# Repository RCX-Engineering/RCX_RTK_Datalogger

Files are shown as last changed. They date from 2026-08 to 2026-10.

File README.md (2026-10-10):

# RCX RTK Datalogger & RCX RTK Base

The **RCX RTK Datalogger**, developed by **RCX Engineering**, is an open-source RTK GNSS data-acquisition system developed for motorsports. The project combines a 20 Hz quad-band omni-constellation GNSS receiver, 6-axis IMU, vehicle CAN data, local SD logging, an onboard display, Wi-Fi connectivity for RTCM (RTK) data, a web interface for device management, and Bluetooth (BLE) telemetry compatible with the RaceCapture protocol for connectivity to datalogging software like SoloStorm.

The repository contains firmware for two closely related devices:

- **RCX RTK Datalogger (rover)** — installed in the vehicle to acquire GNSS, IMU, and CAN data and stream/log the resulting telemetry.
- **RCX RTK Base** — a portable reference station that generates RTK correction data for use where a suitable nearby public base is unavailable.

The rover and base share identical hardware. Their primary difference is the firmware and the interfaces enabled for each role.

> **Project status:** The RCX RTK Datalogger and RCX RTK Base are actively developed engineering/prototype platforms. They have been tested in real autocross environments, but hardware, firmware, configuration, and data-processing methods continue to evolve. 

## What Is RTK GNSS?

**GNSS** (Global Navigation Satellite System) is the general term for satellite-positioning systems such as GPS, Galileo, GLONASS, and BeiDou. A conventional standalone GNSS receiver calculates its position from the timing and ranging information broadcast by the satellites. Even with a good modern multi-band receiver, the resulting position still contains errors from satellite clocks and orbits, atmospheric propagation, multipath, receiver noise, and satellite geometry.

**RTK — Real-Time Kinematic — GNSS adds a fixed reference base station at a known location.** The base observes many of the same satellites and many of the same error sources as the moving rover. It generates correction data and sends it to the rover, typically as an RTCM stream over a radio or an Internet-based NTRIP connection. The rover combines those corrections with multi-frequency carrier-phase measurements and resolves the carrier-cycle ambiguities required for an **RTK Fixed** solution.

The important difference is scale: ordinary standalone GNSS positioning is generally a **meter-scale** measurement, while a good RTK Fixed solution can provide **centimeter-scale relative positioning**. The exact accuracy is installation and environment-dependent, and absolute accuracy also depends on how accurately the base position is known.

| | Standalone GNSS | RTK GNSS |
|---|---|---|
| Reference station | Not required | Required, directly or through an RTK network |
| Correction data | None | Real-time base/network corrections |
| Primary measurements | Satellite ranging; receiver-dependent use of carrier data | Multi-frequency carrier-phase positioning with corrections |
| Typical positioning scale | Meter level | Centimeter level when RTK Fixed |
| Sensitivity to multipath/obstruction | Significant | Still significant; RTK cannot eliminate local multipath or blocked satellites |
| Best suited for | Navigation, timing, general track mapping | Precise trajectory comparison, surveying, machine control, and high-resolution motorsports analysis |

For motorsports, the benefit is not simply a prettier GPS trace. When two runs differ by only a few inches at an apex or slalom cone, meter-scale position uncertainty can be larger than the driving difference being studied. Centimeter-class RTK data makes those differences directly measurable and substantially improves confidence when correlating vehicle position with IMU and CAN data.

RTK also improves **repeatability**: data from different runs, vehicles, or days can be placed in the same coordinate frame when they use a properly established reference. This enables meaningful comparison of line choice, cone clearance, braking and acceleration locations, vehicle attitude, and derived quantities such as wheel trajectories and slip behavior.

RTK does **not** inherently mean a high update rate. Position accuracy and sample rate are separate characteristics. The RCX RTK Datalogger combines RTK positioning with **20 Hz** GNSS output specifically so that centimeter-scale position information is also sampled fast enough for highly transient autocross maneuvers.

## Why RTK Datalogging?

Conventional consumer GNSS logging is often adequate for lap timing and broad vehicle-path visualization, but its positional uncertainty can be large relative to the differences that matter in autocross: inches of line placement, distance from a cone, small changes in corner entry, and vehicle attitude during transient maneuvers.

The RCX RTK Datalogger was developed to combine high-rate RTK positioning with vehicle and inertial data in a single inexpensive, reproducible platform. The resulting data supports applications such as:

- high-resolution racing-line comparison;
- cone-relative path and clearance analysis;
- vehicle orientation and yaw analysis;
- oversteer/understeer and slip-angle analysis;
- correlation of GNSS, IMU, and CAN data;
- course reconstruction and 3D visualization;
- development of higher-fidelity empirical vehicle models.

## System Architecture
| File | Purpose |
|---|---|
| [`RCX_RTK_Datalogger-schematic_viewer.html`](https://rcx-engineering.github.io/RCX_RTK_Datalogger/schematics/RCX_RTK_Datalogger-schematic_viewer.html) | Engineering model viewer for the hardware and wiring configuration. |
| [`RCX_RTK_Datalogger - Firmware Schematic Viewer.html`](https://rcx-engineering.github.io/RCX_RTK_Datalogger/schematics/RCX_RTK_Datalogger%20-%20Firmware%20Schematic%20Viewer.html) | Engineering model viewer for the firmware architecture. |
```text
                         ┌──────────────────────┐
                         │     RCX RTK Base     │
                         │                      │
                         │ ESP32-S3 + LG290P    │
                         │ survey / reference   │
                         └──────────┬───────────┘
                                    │ RTK correction stream
                                    ▼
                         ┌──────────────────────┐
                         │     NTRIP caster     │
                         │  Centipede / RTK2go  │
                         └──────────┬───────────┘
                                    │ Wi-Fi / Internet
                                    ▼
┌──────────────┐         ┌──────────────────────────────┐
│ Vehicle CAN  ├────────►│   RCX RTK Datalogger         │
└──────────────┘         │                              │
                         │ ESP32-S3-LCD-1.47B           │
                         │ LG290P RTK GNSS @ 20 Hz      │
                         │ onboard QMI8658 6-axis IMU   │
                         │ TWAI / CAN interface         │
                         │ SD logging                   │
                         │ LCD + web UI                 │
                         └─────────┬───────────┬────────┘
                                   │           │
                          Bluetooth│           │ local files/UI
                                   ▼           ▼
                            ┌────────────┐   SD / browser
                            │ SoloStorm  │
                            │RaceCapture │
                            │ protocol   │
                            └────────────┘
```

### RCX RTK Datalogger

The rover firmware is designed for motorsports data logging and currently integrates:

- **20 Hz RTK GNSS** using the Waveshare/Quectel LG290P;
- **6-axis inertial data** from the QMI8658 IMU;
- **vehicle CAN acquisition** through the ESP32-S3 TWAI peripheral and an external CAN transceiver;
- **DBC-based CAN decoding**;
- **RaceCapture-compatible Bluetooth telemetry** for SoloStorm;
- **MicroSD logging** for local high-rate data capture;
- **on-device status display**;
- **embedded web interface** for status and configuration;
- **Wi-Fi/NTRIP correction handling**;
- watchdog and resource-management logic for an aggressively loaded ESP32-S3 platform.

Current vehicle-specific CAN work has primarily been developed and validated around Porsche 987.2 S PDK and 718 PDK platforms. DBC support is intended to make the CAN layer extensible to other vehicles and signal definitions.

### RCX RTK Base

The RCX RTK Base firmware uses the same general ESP32-S3/LG290P hardware platform as the RCX RTK Datalogger but configures it as a stationary RTK reference source.

The base has been developed to:

- establish a reference position for the GNSS receiver;
- use PPP/Galileo E6-HAS information as part of the custom survey-in workflow;
- generate RTK correction data;
- publish corrections through NTRIP casters;
- provide local status information and logging for base health and stability.

Development testing has used both **Centipede** and **RTK2go** NTRIP services. A single correctly configured base can provide correction data to multiple compatible rovers within the practical RTK baseline and communications limits.

## Measured Performance

The RCX RTK Datalogger has produced centimeter-class dynamic GNSS solution quality in motorsports testing, with substantially tighter stationary solution scatter under favorable conditions.

Representative results reported during development include:

| Test | Reported result |
|---|---:|
| 30-minute stationary test | **1.6 mm 1σ positional scatter** |
| Bristol National Tour, on course | **~1.9 cm mean reported accuracy** |
| NCCAR autocross, on course | **1.6 cm median reported accuracy** |
| NCCAR autocross, on course | **2.4 cm 95th-percentile reported accuracy** |

These values are representative test results, not guaranteed performance. GNSS performance remains dependent on satellite geometry, correction quality, antenna installation, multipath, obstructions, RF environment, RTK fix state, and base-station quality. The reported solution metrics also should not be interpreted as an independent surveyed ground-truth error measurement.

## Hardware

The reference implementation is based on the following hardware.

### Core hardware

- **Waveshare ESP32-S3-LCD-1.47B**
  - ESP32-S3
  - onboard QMI8658 IMU
  - onboard LCD
  - PSRAM required by the current firmware
- **Waveshare LG290P RTK GNSS development board**
  - LG290P firmware **v2.02 or newer** required
  - tested package: `LG290P03AANR02A02S.pkg`
- multi-band GNSS antenna
- MicroSD card
- USB power

### RCX RTK Datalogger-specific hardware

- **SN65HVD230 CAN transceiver board** or equivalent compatible 3.3 V CAN interface
- vehicle CAN harness/tap
- appropriate termination configuration for the vehicle network

The reference SN65HVD230 development board is used with its onboard **120 Ω termination resistor removed** when attaching to an already terminated vehicle CAN bus.

### Recommended supporting hardware

- GNSS RTC backup battery for faster hot starts;
- small cooling fan for sustained high-load operation;
- 3D-printed enclosure and mounting hardware;
- suitable multi-band antenna with good multipath rejection.

A helical antenna has performed better than the original patch antenna in some real autocross environments with substantial multipath and dynamic obstruction, although antenna choice and mounting should be treated as installation-specific engineering decisions.

## Firmware Build Environment

The firmware is built with the **Arduino IDE**.

The rover build has been validated with:

- **ESP32 by Espressif Systems 3.3.8**
- board target: **ESP32S3 Dev Module**
- 16 MB flash
- QIO 80 MHz flash mode
- OPI PSRAM
- 240 MHz CPU
- `Huge APP (3MB No OTA/1MB SPIFFS)` partition scheme
- USB CDC on boot enabled

The current rover firmware depends on the ESP32 Arduino Core 3.x APIs and memory layout; earlier core releases are not supported.

### RCX RTK Datalogger libraries

The rover currently uses:

- `TFT_eSPI` — Bodmer
- `NimBLE-Arduino` 2.x — h2zero
- `TinyGPSPlus` — Mikal Hart
- `ESP Async WebServer` — ESP32Async
- `AsyncTCP` — ESP32Async

Wi-Fi, Wire/I2C, SD_MMC, Preferences, TWAI, and watchdog support are provided by the ESP32 Arduino core. The QMI8658 is driven directly over I2C.

## Engineering Knowledge Graphs Are Source Code

This repository also contains **OpenCypher knowledge-graph models developed by RCX Engineering for the RCX RTK Datalogger and RCX RTK Base wiring and system architecture**.

These graph models are considered part of the project source code, not merely supplemental documentation. They provide a machine-readable representation of the engineered system, including relationships among hardware components, interfaces, wiring, buses, data paths, and architectural elements.

The intent is for the knowledge graph to serve alongside the firmware as an authoritative engineering artifact that can support:

- architecture queries and design review;
- wiring/interface traceability;
- consistency checking between hardware and software;
- automated engineering analysis;
- impact analysis when components or interfaces change;
- future AI/agent-assisted engineering workflows.

Changes to the physical or logical architecture should therefore include corresponding updates to the OpenCypher model where applicable.

## Data and Interfaces

### GNSS

The rover is designed around 20 Hz LG290P position output and RTK corrections delivered over NTRIP. RTK fixed operation is the normal target state for high-precision motorsports analysis.

### IMU

The onboard QMI8658 provides six-axis inertial measurements. IMU data are logged alongside GNSS and CAN so that vehicle motion can be analyzed in a common time history.

### CAN

Vehicle CAN is acquired through the ESP32-S3 TWAI controller. DBC decoding is supported so that raw CAN traffic can be converted into engineering channels without hard-coding every signal into the application.

Connecting experimental hardware to a vehicle CAN network requires care: incorrect wiring, termination, shorts, or transceiver faults can disrupt vehicle communications.

Porsche 987.2 and 718 were used for development and their CAN addresses are hardcoded and automatically recognized. Other vehicles are supported by uploading a .dbc file with vehicle specific CAN data.

A CAN sniffer tool is integrated into the rover and may be used to capture and save the raw CAN data stream to the MicroSD card to aid users in identifying available data channels.

### Bluetooth / SoloStorm

The rover implements the published **RaceCapture** communication format over Bluetooth so that supported telemetry can be consumed by software like SoloStorm while the full data set is also retained locally.

### Local Logging

MicroSD logging provides a source independent of the live Bluetooth connection and is intended for engineering analysis, debugging, and preservation of higher-detail data.

## Base-Station and RTK Considerations

RTK quality depends on both ends of the system. A high-quality rover cannot compensate for a poor reference position, interrupted RTCM stream, excessive base-to-rover separation, or severe local multipath.

Development of the RCX RTK Base has therefore focused on both position establishment and operational stability. PPP-assisted survey-in was added to improve the quality of a temporary base position when a surveyed reference point is not available.

For repeat events, a previously established high-quality reference position is generally preferable to treating every setup as an unrelated new base location.

## Known Limitations / Active Development Areas

The RCX RTK Datalogger and RCX RTK Base have been deliberately pushed close to the resource and thermal limits of the ESP32-S3. Areas that have required active development include:

- thermal management under sustained load;
- task scheduling and prioritization;
- simultaneous base casting and SD logging;
- GNSS multipath and dynamic occlusion;
- transitions between RTK fixed and RTK float;
- antenna placement and phase-center effects;
- reliability of external NTRIP services;
- vehicle-specific CAN decoding;
- dead-reckoning and GNSS-outage handling.

These are important engineering characteristics of the project, not hidden failure modes. Contributions that improve robustness, portability, diagnostics, or validation are welcome.

## Building and Configuration

1. Install the Arduino IDE.
2. Install **ESP32 by Espressif Systems 3.3.8**.
3. Select **ESP32S3 Dev Module** and configure flash/PSRAM/partition settings as documented in the firmware-specific README.
4. Install the required libraries.
5. Build and flash the appropriate **rover** or **base-station** firmware.
6. Connect to the wifi SSID shown on the LCD 
7. Browse to the IP address shown on the LCD, http://192.168.4.1 or http://192.168.5.1 and add the desired wifi SSIDs annd passwords. *Note: Use http, not https; encryption is not yet implemented.*
8. If a private base is used, configure the base and datalogger for the same NTRIPS service and host name.
9. Configure the tablet datalogger to connect to your new datalogger via RaceCapture format.

## Contributing

Issues, test data, DBC definitions, hardware-porting improvements, GNSS/base-station validation, documentation fixes, and pull requests are welcome.

When modifying the system architecture, please treat the firmware, wiring definitions, and OpenCypher knowledge graph as coordinated source artifacts and update all affected representations together.

## Project History

The RCX RTK Datalogger and RCX RTK Base grew from a DIY motorsports data-logging experiment in May 2026 into a combined rover/base RTK platform through iterative static testing, autocross competition use, CAN reverse engineering, GNSS/antenna testing, and firmware optimization.

## Acknowledgments

The RCX RTK Datalogger and RCX RTK Base build on open protocols, open-source libraries, community reverse engineering, and the work of the developers who make the ESP32, GNSS, Bluetooth, web-server, and motorsports data ecosystems accessible to hobbyist engineering projects.

In particular, the project uses the published **RaceCapture protocol from Autosport Labs** for motorsports telemetry interoperability and referenced [**Racepi**](https://github.com/donour/racepi) code developed to implement RaceCapture protocol on an open source Raspberry Pi datalogger.

## License

See [LICENSE](LICENSE) for the terms that apply to this repository.

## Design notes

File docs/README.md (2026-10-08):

# RCX RTK Datalogger Schematics & Knowledge Graph

This directory contains the interactive wiring and architecture model for the **RCX RTK Datalogger**, developed by **RCX Engineering**.

These files are not conventional static schematics. Each HTML file contains a self-contained **OpenCypher labeled property graph** describing the physical and logical wiring and firmware architectures, together with JavaScript that renders the graph into interactive engineering views. These are interactive viewers designed to aid design and troubleshooting and are historic as the the first published generative model-based engineering knowledge graph for electrical design using new methods proposeed by NASA and shared with NASA's Text-to-Spaceship team.

## Interactive Viewers

| File | Purpose |
|---|---|
| [`RCX_RTK_Datalogger-schematic_viewer.html`](https://rcx-engineering.github.io/RCX_RTK_Datalogger/docs/RCX_RTK_Datalogger-schematic_viewer.html) | Engineering model viewer for the hardware and wiring configuration. |
| [`RCX_RTK_Datalogger-firmware_architecture_viewer.html`](https://rcx-engineering.github.io/RCX_RTK_Datalogger/docs/RCX_RTK_Datalogger-firmware_architecture_viewer.html) | Engineering model viewer for the firmware / software architecture. |

## Knowledge Graph Model

The OpenCypher models in these files are considered part of the **RCX RTK Datalogger source code**, not merely documentation. The full graph models are embedded in the html viewers for convenience; both model and viewer must be updated simultanously.

The graphs are intended to be a machine-readable engineering definition of the system architecture. They captures relationships among devices, connectors, pins, harnesses, electrical nets, functions, and physical wiring in a form that can be queried, validated, transformed, or used to generate other engineering artifacts.

---

**RCX Engineering**  
RCX RTK Datalogger

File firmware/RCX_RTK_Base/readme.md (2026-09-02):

This is the source code for the RTK Base ntrips caster. This will need to be configured prior to use. 

We recommend public casters use Centipede for Europe and rtk2go in the US, though both are global.
rtk2go is unforgiving of configuration errors and quick to temporarily ban ips: 
  Test with a temporary unpublished Centipede mount point before establishing a permanant. 

See the documentation from Centipede and rtk2go for more details. 
Centipede Mount Points are 4-5 characters, letters and numbers only.

See the build notes for the RCX_RTK_Datalogger: (The hardware and wiring is identical aside from no need for a CAN adapter in the base.)

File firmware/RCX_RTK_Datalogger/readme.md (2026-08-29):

This is the firmware for the rover. It's designed for motorsports data logging of 20Hz GNSS, IMU, and CAN data using the RaceCapture protocol published by Autosports Labs.

## Hardware 
### Waveshare ESP32-S3-LCD-1.47B
Other variants may work but are untested. Note: IO/GPIO vary greatly betweeen ESP32 variants, even similar ones, and must be remapped

### Waveshare LG290P RTK GNSS Dev Board
LG290P must be on v2.02 firmware or newer. (LG290P03AANR02A02S.pkg)

## Building the firmware
Built with the Arduino IDE http://arduino.cc/en/software

### Board package

Add to *File → Preferences → Additional Boards Manager URLs*: https://raw.githubusercontent.com/espressif/arduino-esp32/gh-pages/package_esp32_index.json
Then install **esp32 by Espressif Systems, version 3.3.8**. Other 3.x versions may work; earlier versions will not — the firmware relies on core 3.x APIs and memory layout.

### Board settings

Select **ESP32S3 Dev Module** (not the Waveshare board entry — it hides the PSRAM option, which the firmware requires).

| Setting | Value |
|---|---|
| Flash Size | 16MB |
| Flash Mode | QIO 80MHz |
| PSRAM | OPI PSRAM |
| Partition Scheme | Huge APP (3MB No OTA/1MB SPIFFS) |
| USB CDC On Boot  | Enabled |
| USB DFU On Boot  | Disabled |
| CPU Frequency | 240MHz |
| Upload Speed | 921600 |

**Change the partition scheme.**
- Go to *Tools → Partition Scheme* and select **Huge APP (3MB No OTA/1MB SPIFFS)**.
- If you need OTA, *Minimal SPIFFS (1.9MB APP with OTA/190KB SPIFFS)* retains it, but has not been tested and may not support future upgrades.

### Libraries

Install from the Library Manager:

| Library | Author |
|---|---|
| TFT_eSPI | Bodmer |
| NimBLE-Arduino (2.x) | h2zero |
| TinyGPSPlus | Mikal Hart |
| ESP Async WebServer  | ESP32Async |
| AsyncTCP | ESP32Async |

The web server libraries must be the **ESP32Async** forks. The original me-no-dev versions do not compile against core 3.x. If both are present the IDE picks the wrong one — delete `Arduino/libraries/ESPAsyncWebServer` and `Arduino/libraries/AsyncTCP`, keeping `ESP_Async_WebServer` and `Async_TCP`.

WiFi, Wire, SD_MMC, Preferences, TWAI and the task watchdog come from the core. The QMI8658 IMU is driven directly over I2C and needs no library.

### Display configuration

Copy `TFT_UserSetup.h` from this repository over `Arduino/libraries/TFT_eSPI/User_Setup.h`, and confirm that `User_Setup_Select.h` has only `#include <User_Setup.h>` uncommented.
`TFT_BL` is intentionally left undefined. The backlight is on GPIO46 and is driven by the sketch through LEDC; declaring it to TFT_eSPI as well produces a boot-time IO 46 conflict.

### Hardware notes

The LG290P GNSS module connects to GPIO4 (RX) and GPIO5 (TX) at 460800 baud. If the COM port does not appear, install the Silicon Labs CP2102 driver. If upload stalls at "Connecting…", hold BOOT while connecting USB.

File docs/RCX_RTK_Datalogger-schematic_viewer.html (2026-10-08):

KG Schematic Viewer

# Loading graph…

DrawingTables

Physical pin locations Wire colours Unconnected pins Net labels Wire tags

Showing your edited graph, not the one embedded in this page.Revert to embedded

−100%+Fit

Loading the layout engine…

Open graph… Apply revision… Revert Copy Cypher Copy page with this graph Copy SVG

Embedded

Edits redraw as you type. A revision file is appended below the current graph, so MATCH … SET, MERGE and DETACH DELETE statements in it change what is already here. Your edits stay in this browser until you revert.

Reset rules

Rules applied

Rules decide what the graph means on paper: which labels are pins and connectors, which relationships are wires, mates or taps, which ones only join nets, what encloses what, and which KiCad symbol each part uses. {n} in a symbol name is the contact count; {key} reads a node property.

Add KiCad library…

Symbols come from the KiCad library files embedded in this page. Add any .kicad_sym file from your KiCad install to make more symbols available to the rules.

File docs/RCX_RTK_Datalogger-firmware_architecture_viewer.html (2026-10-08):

KG Architecture Viewer

# Loading graph…

Descriptions Edge labels

Showing your edited graph, not the one embedded in this page.Revert to embedded

−100%+Fit

Loading the layout engine…

Open graph… Apply revision… Revert Copy Cypher Copy SVG

Embedded

Edits redraw as you type. A revision file is appended below the current graph, so MATCH … SET, MERGE and DETACH DELETE statements in it change what is already here. Your edits stay in this browser until you revert.

Reset rules

Rules applied

Rules decide what the graph means as architecture: which label plays which role, which relationships each view draws, what nests inside what, and which properties become titles, fields, meters and status. {key} reads a node or relationship property; a list of templates uses the first whose properties are all present.

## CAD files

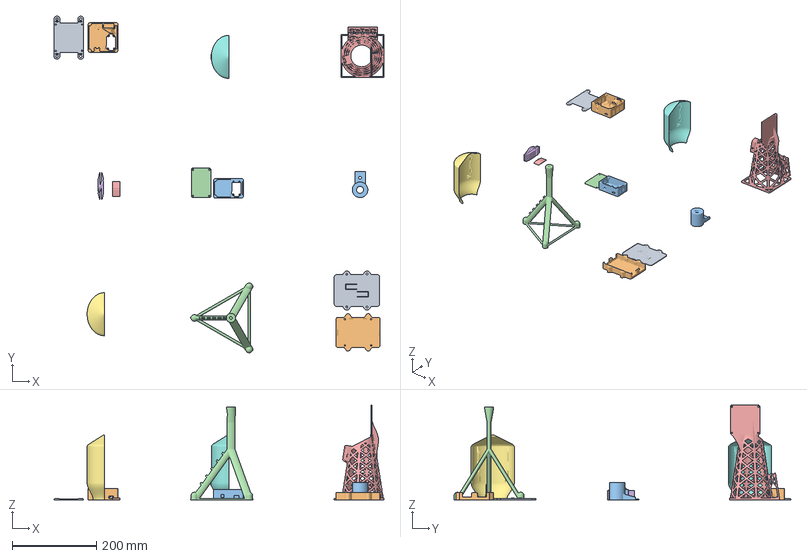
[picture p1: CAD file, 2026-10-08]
enclosure/RCX_RTK_Datalogger_3D_Printing_Models.3mf
783.4 x 799.4 x 225.4 mm
RCX_lid_artwork_inlay
RCX_base_engraved
esp32_lg290p_enclosure_bosl2_v9.stl
esp32_lg290p_enclosure_bosl2_v5 - lid.stl
Antenna cable protector.stl
GNSS_trunk_edge_cable_protector_clip_v5.stl
RCX_rain_sun_shroud_v2.7.step
RCX_rain_sun_shroud_v2.8-antenna.step
RCX_battery_cover_v2.stl
RCX_battery_tray_v2.stl
antenna_tripod_v21.stl
RCX_cone_positioning_lid_v13.step

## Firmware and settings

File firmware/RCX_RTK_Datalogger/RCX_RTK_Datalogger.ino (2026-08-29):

/*
 * RCX_RTK_Datalogger.ino — Main sketch
 * ===================================
 * Hardware: Waveshare ESP32-S3-LCD-1.47B
 *           + Waveshare LG290P GNSS RTK module
 *           + SN65HVD230 CAN transceiver (built-in TWAI, see config.h for pins)
 *
 * What this does:
 *   - Reads GPS/GNSS from LG290P via UART (NMEA + PQTMEPE)
 *   - Reads IMU from onboard QMI8658 (accel + gyro at 1kHz)
 *   - Reads CAN via built-in TWAI (listen-only) at 20Hz
 *   - Connects to WiFi, pulls NTRIP RTK corrections, pipes to LG290P
 *   - Streams GPS+IMU+CAN channels in RaceCapture format over BLE
 *   - Logs everything to SD card (gps_*.csv + sat_*.csv)
 *   - Serves a web dashboard at http://<device-ip>/
 *
 * Libraries (install via Arduino Library Manager):
 *   NimBLE-Arduino, TinyGPSPlus, TFT_eSPI,
 *   ESP Async WebServer, AsyncTCP
 *   (driver/twai.h is built into arduino-esp32 — no extra install needed)
 *
 * Before compiling:
 *   1. Copy TFT_UserSetup.h into your TFT_eSPI library as User_Setup.h
 *   2. Edit config.h for your WiFi, NTRIP, and CAN pin assignments
 *   3. Wire the SN65HVD230 to CAN_RX_PIN/CAN_TX_PIN listed in config.h
 *   4. Remove the 120 Ohm surface-mount resistor from SN65HVD230 CAN transciever
 *
 * Task layout:
 *   Core 1 (main): setup() + loop() — BLE TX, IMU read, display, GNSS parse
 *   Core 0:        wifiNtripTask    — WiFi, NTRIP, RaceCapture TCP server
 *   Core 0:        canBusTask       — TWAI listen-only at 500kbps, 20 Hz drain
 *   Core 0:        sdLogTask        — SD card writes (optional)
 *
 * ── Forward declarations (Arduino IDE needs these before the .cpp files) ──────
 */

struct GnssData;
struct ImuData;
struct SystemStatus;
struct CanData;
struct LogRecord;
// NtripConnResult is declared in ntrip.h — no forward-decl needed here

// ── Module includes ────────────────────────────────────────────────────────────
#include "config.h"
#include "types.h"
#include "gnss.h"
#include "imu.h"
#include "can_bus.h"
#include "ble_racecapture.h"
#include "racecapture.h"
#include "ntrip.h"
#include "wifi_mgr.h"
#include "display.h"
#include "thermal.h"
#include "sd_log.h"
#include "dbc_store.h"
#include "webserver.h"
#include <WiFi.h>
#include <esp_heap_caps.h>   // internal-heap diagnostics (heapTrace + 30s watermark)
#include <esp_system.h>      // esp_reset_reason() — boot cause for thermal-restart diagnosis
#include <driver/temperature_sensor.h>   // see dieTempReadWideC() — Arduino's own temperatureRead()
                                          // requests too narrow a range for this project's use
// debug_log.h LAST on purpose: when DEBUG_SERIAL_TO_SD is on it defines
// `#define Serial Debug`, and that must not rewrite the token inside any system
// or library header. Placed after every other include, the macro only affects
// this .ino's own code below — which is exactly what we want to tee.
#include "debug_log.h"

// ── Global shared state — declared extern in types.h ──────────────────────────
GnssData      gps;
ImuData       imu;
CanData       can;
SystemStatus  status;
SemaphoreHandle_t dataMutex = nullptr;

// rtcmBytesTotal declared extern in types.h, defined in ntrip.cpp

// ── Internal-RAM low-water tracking ───────────────────────────────────────────
// Sampled fast in loop() (catches dips a 5 s status poll misses). g_minFreeInternal
// = lowest total internal SRAM free ever; g_minLargestBlock = lowest largest
// contiguous block (fragmentation guard — TCP/SD allocs need contiguous memory).
// /status reports both (extern'd in webserver.cpp) so you get a hours-long record.
volatile uint32_t g_minFreeInternal = 0xFFFFFFFF;
volatile uint32_t g_minLargestBlock = 0xFFFFFFFF;

// DMA-capable is a narrower pool than general internal SRAM (MALLOC_CAP_DMA vs
// MALLOC_CAP_INTERNAL) — it's specifically what the SD driver's per-sector
// bounce buffer and WiFi's own buffers draw from (see printlnRetry() in
// sd_log.cpp). Tracked the same way, separately, because the general figures
// above have been observed reading a normal ~28-30 KB at the exact moment a
// write failed — this is the pool that actually explains that.
volatile uint32_t g_minFreeDma    = 0xFFFFFFFF;
volatile uint32_t g_minLargestDma = 0xFFFFFFFF;

// Last reset reason as text — captured once in setup(), declared extern in types.h.
// Read by sd_log (boot_events.csv) and webserver (/status). See types.h for why.
char g_resetReasonStr[32] = "unknown";

// ── GPS UART ──────────────────────────────────────────────────────────────────
HardwareSerial gpsSerial(1);   // UART1

// ── Display task (Core 0) ────────────────────────────────────────────────────
// Display SPI is slow (~15-30ms per redraw). Running it here instead of in
// loop() keeps that blocking off Core 1, so GNSS UART draining and BLE
// streaming are never stalled by a screen refresh. The task snapshots shared
// state under the mutex, then does all SPI work WITHOUT holding the lock.
// Only this task ever touches the TFT, so there is no display-bus contention.
static void displayTask(void*) {
    for (;;) {
        GnssData g_snap; ImuData m_snap; SystemStatus s_snap;
        if (xSemaphoreTake(dataMutex, pdMS_TO_TICKS(10))) {
            g_snap = gps; m_snap = imu; s_snap = status;
            xSemaphoreGive(dataMutex);
        }
        display_update(g_snap, m_snap, s_snap);   // internally rate-limited to 5 Hz
        vTaskDelay(pdMS_TO_TICKS(50));            // poll at 20 Hz; redraw gate is inside
    }
}

// Per-step internal-heap trace. Internal SRAM (not PSRAM) is what SDMMC DMA
// buffers and TCP sockets need. File-scope (not setup()-local) because the real
// startup sequence — WiFi AP/STA bring-up, the webserver's actual listener bind,
// NTRIP init, the RaceCapture server — all run inside wifiNtripTask, not setup(),
// and none of it was ever traced before. See that function for why this mattered:
// every heap sample this project has ever logged already reflects whatever these
// four calls cost, with no visibility into which one actually costs it.
static void heapTrace(const char* step) {
    Serial.printf("🔍 [heap] after %-12s internal=%6u B (largest block %6u B)\n",
        step,
        (unsigned)heap_caps_get_free_size(MALLOC_CAP_INTERNAL | MALLOC_CAP_8BIT),
        (unsigned)heap_caps_get_largest_free_block(MALLOC_CAP_INTERNAL | MALLOC_CAP_8BIT));
}

// ── WiFi/NTRIP/RaceCapture task (Core 0) ─────────────────────────────────────
static void wifiNtripTask(void*) {
    heapTrace("task start");
    ntrip_init();
    heapTrace("ntrip_init");

    // Configuration AP first. This task is created after gnss_init() has fully
    // completed, which is the earliest point the radio may legally come up (see
    // the ordering note in setup()). The AP is the only route to the dashboard
    // on a unit with no stored networks, and it stays up for as long as the
    // station search is still running.
    wifi_apBegin();
    heapTrace("wifi_apBegin");

    // Initial WiFi connect. Returns false with an empty station list — that is
    // normal AP-only operation, not a failure, so the servers below still start.
    bool connected = wifi_tryConnect();
    heapTrace("wifi_tryConnect");

    // The dashboard must come up whether or not a station link exists: on a unit
    // with no stored networks the AP is the ONLY way to reach it, and adding the
    // first network is done from that dashboard. Binding the listen socket while
    // AP-only is safe: the AP netif is already up from wifi_apBegin() above, and
    // the radio mode is never re-entered afterwards, so the socket is never
    // orphaned by an interface rebuild (see wifi_mgr.cpp).
#if defined(WEBSERVER_ENABLE) && WEBSERVER_ENABLE
    webserver_begin();
    heapTrace("webserver_begin");
#endif
    // The RaceCapture telemetry server is only meaningful to an app on the same
    // network, but the AP is a network — start it in both cases too.
#if defined(RACECAPTURE_ENABLE) && RACECAPTURE_ENABLE
    racecapture_beginServer();
    heapTrace("racecapture_begin");
#endif
    (void)connected;

    static bool wifiWasUp = false;

    for (;;) {
        // Track the AP against station state: up while disconnected, down once a
        // station link has held (see wifi_apService).
        wifi_apService();

        // ── WiFi watchdog ─────────────────────────────────────────────────
        if (WiFi.status() != WL_CONNECTED) {
            if (wifiWasUp) {
                // Down-edge: run cleanup exactly once, not every retry cycle.
                wifiWasUp = false;
                if (xSemaphoreTake(dataMutex, portMAX_DELAY)) {
                    status.wifiConnected  = false;
                    status.ntripConnected = false;
                    status.rcConnected    = false;
                    xSemaphoreGive(dataMutex);
                }
                ntrip_onWifiLost();   // soft: keep mountpoint, prompt retry on return
            }

            // wifi_service() owns all reconnect policy and timing: the loyalty
            // window on the network that just dropped, the restart of the full
            // priority search when that window expires, and the spacing between
            // sweeps. It is a cheap no-op when there is nothing to attempt, so
            // it is safe to call on every pass of this loop.
            if (wifi_service()) {
                wifiWasUp = true;     // up-edge after a drop
#if defined(RACECAPTURE_ENABLE) && RACECAPTURE_ENABLE
                racecapture_beginServer();
#endif
            }
        } else {
            wifiWasUp = true;
        }

        if (WiFi.status() == WL_CONNECTED) {
            // Snapshot GPS for NTRIP and RaceCapture (mutex held briefly).
            // On a failed take, SKIP the consumers this pass rather than feed
            // them default-constructed (all-zero) snapshots: a zeroed GnssData
            // reads as epochSeq=0 to the BLE epoch detector (a phantom "new
            // epoch" carrying garbage data) and as a 0,0 position to any GGA
            // the NTRIP session sends. The next pass is 10 ms away; every
            // consumer tolerates that far better than fabricated data.
            GnssData g_snap; ImuData m_snap; CanData c_snap;
            bool snapOk = false;
            if (xSemaphoreTake(dataMutex, pdMS_TO_TICKS(5))) {
                g_snap = gps; m_snap = imu; c_snap = can;
                xSemaphoreGive(dataMutex);
                snapOk = true;
            }

            if (snapOk) {
                ntrip_loop(gpsSerial, g_snap);

#if defined(RACECAPTURE_ENABLE) && RACECAPTURE_ENABLE
                racecapture_loop(g_snap, m_snap, c_snap);
#endif
            }
        }

        delay(10);
    }
}
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
void loop() {
    uint32_t loopT0 = micros();

    // ── GNSS: parse UART bytes, update gps struct ─────────────────────────
    LOOP_PHASE(GNSS, gnss_loop(gpsSerial));

    // ── IMU: read at 50 Hz into a local, then publish under mutex ─────────
    {
        static uint32_t lastImu = 0;
        if (millis() - lastImu >= 20) {
            lastImu = millis();
            imu_pollSerial();                        // "imucal" → start calibration (no-op otherwise)
            imu_serviceCalRequests();                // web /imu/cal → start/clear, same context as imu_read()
            ImuData m_local;
            LOOP_PHASE(IMU, imu_read(m_local));      // blocking I2C — done WITHOUT the mutex
            if (xSemaphoreTake(dataMutex, pdMS_TO_TICKS(5))) {
                imu = m_local;                        // publish atomically
                xSemaphoreGive(dataMutex);
            }
            // Push IMU record at 50 Hz to its own SD log channel
            sdlog_push_imu(m_local.ax, m_local.ay, m_local.az,
                           m_local.gx, m_local.gy, m_local.gz);
        }
    }

    // ── Device temperature at 0.5 Hz ──────────────────────────────────────
    // The ESP32-S3 die sensor (dieTempReadWideC, defined above loop()) is a quick
    // internal-ADC read with no bus involved. 0.5 Hz is ample for thermal work.
    // Published under the mutex so the GPS log, /status and the display all read a
    // consistent snapshot.
    {
        static uint32_t lastTemp = 0;
        if (millis() - lastTemp >= 2000) {
            lastTemp = millis();
            uint32_t tempT0 = micros();
            float espC = dieTempReadWideC();         // ESP32-S3 silicon die, °C
            thermal_update(espC);                    // see thermal.h — LCD/SD throttling only
            loopPhase::note(loopPhase::TEMP, micros() - tempT0);
            if (xSemaphoreTake(dataMutex, pdMS_TO_TICKS(5))) {
                status.espTempC = espC;
                xSemaphoreGive(dataMutex);
            }
        }
    }

    // ── BLE: RaceCapture command replies every pass; samples self-limited ──
    // The 40 ms window that used to wrap this gated command replies too. But
    // SoloStorm fires {"getMeta":null} repeatedly and impatiently right after
    // subscribe and will spin/disconnect if the {"meta":[...]} reply lags. So
    // tick() now runs EVERY loop pass: it drains ACKs + pendingMeta promptly,
    // while sendSample() inside tick() keeps its own 50 ms (20 Hz) rate gate —
    // emitting samples no faster than before. Only the reply latency improves.
    {
        // Snapshot shared state under the mutex ONLY (see note below). On a
        // timed-out take, reuse the last good snapshot rather than skipping.
        //
        // ⚠️ ble_racecapture_tick() MUST run unconditionally, NOT gated on the
        //    mutex AND NOT gated on a sample-rate window. It drains command
        //    ACKs and pendingMeta/pendingVersion. If it is skipped (5 ms take
        //    failed, or a coarse rate window), pendingMeta is set but never
        //    sent — SoloStorm re-requests getMeta forever and spins.
        //    (Field log: repeated "BLE RX: getMeta" with no TX, then disconnect.)
        //    tick() does BLE notify()s with vTaskDelays, so it must run OUTSIDE
        //    the critical section. Snapshot in, tick out.
        static GnssData g_snap; static ImuData m_snap; static CanData c_snap;
        if (xSemaphoreTake(dataMutex, pdMS_TO_TICKS(5))) {
            g_snap = gps; m_snap = imu; c_snap = can;
            xSemaphoreGive(dataMutex);
        }
        LOOP_PHASE(BLE, ble_racecapture_tick(g_snap, m_snap, c_snap));
    }

    // ── SD log ────────────────────────────────────────────────────────────
#if defined(SD_LOG_ENABLE) && SD_LOG_ENABLE
    LOOP_PHASE(SDPUSH, sdlog_push_if_new());   // queues when gnss_loop flags a new epoch
#endif

    // ── Internal-RAM low-water sampling (~20 Hz) ──────────────────────────
    {
        static uint32_t lastHeapSample = 0;
        if (millis() - lastHeapSample >= 50) {
            lastHeapSample = millis();
            // get_free_size reads maintained per-region counters;
            // get_largest_free_block walks the free-block list of every matching
            // heap under the heap lock. The two are timed separately because
            // only the second scales with fragmentation, and fragmentation
            // climbs all session as the WiFi and BLE stacks cycle buffers.
            uint32_t f = 0, lb = 0;
            LOOP_PHASE(HEAP_FREE,
                       f = heap_caps_get_free_size(MALLOC_CAP_INTERNAL | MALLOC_CAP_8BIT));
            LOOP_PHASE(HEAP_LARGEST,
                       lb = heap_caps_get_largest_free_block(MALLOC_CAP_INTERNAL | MALLOC_CAP_8BIT));
            if (f  < g_minFreeInternal) g_minFreeInternal = f;
            if (lb < g_minLargestBlock) g_minLargestBlock = lb;
            // DMA-capable is a NARROWER pool than general internal SRAM — it's
            // what the SD driver's per-sector bounce buffer actually competes
            // for (see printlnRetry() in sd_log.cpp), and WiFi's own buffers
            // draw from the same pool while a page response streams out. A
            // write has been observed failing while the figures above still
            // read a normal ~28-30 KB, which only makes sense if this specific
            // pool was tighter at that moment than the general one — tracking
            // it separately is what would show that directly next time,
            // instead of inferring it after the fact.
            uint32_t fd = 0, ld = 0;
            LOOP_PHASE(HEAP_FREE,    fd = heap_caps_get_free_size(MALLOC_CAP_DMA));
            LOOP_PHASE(HEAP_LARGEST, ld = heap_caps_get_largest_free_block(MALLOC_CAP_DMA));
            if (fd < g_minFreeDma)    g_minFreeDma    = fd;
            if (ld < g_minLargestDma) g_minLargestDma = ld;
        }
    }

    // ── Loop phase timing report ──────────────────────────────────────────
    // WHOLE captures the entire iteration, so any cost NOT attributed to a named
    // phase above shows up as the difference. Reported on its own 5 s cadence so
    // the numbers stay readable next to the existing wire counters.
    loopPhase::note(loopPhase::WHOLE, micros() - loopT0);
    {
        static uint32_t lastPhaseReport = 0;
        if (millis() - lastPhaseReport >= 5000) {
            lastPhaseReport = millis();
            loopPhase::report();
        }
    }

    // ── Stack + heap diagnostics every 30 s ──────────────────────────────
    // Prints the minimum free stack (high-water mark) for each task, and free
    // heap. A value near 0 means that task nearly overflowed. Remove or gate
    // with DEBUG_WATERMARKS once the firmware is stable.
#if defined(DEBUG_WATERMARKS) && DEBUG_WATERMARKS
    {
        static uint32_t lastWM = 0;
        if (millis() - lastWM >= 30000) {
            lastWM = millis();
            Serial.printf("🔍 Heap: %u B free (internal: %u B, largest block %u B) | Stacks: loop=%u WiFiNTRIP=%u\n",
                (unsigned)esp_get_free_heap_size(),                       // includes PSRAM — misleading alone
                (unsigned)heap_caps_get_free_size(MALLOC_CAP_INTERNAL | MALLOC_CAP_8BIT),
                (unsigned)heap_caps_get_largest_free_block(MALLOC_CAP_INTERNAL | MALLOC_CAP_8BIT),
                (unsigned)uxTaskGetStackHighWaterMark(nullptr),   // loop() task
                (unsigned)uxTaskGetStackHighWaterMark(
                    xTaskGetHandle("WiFiNTRIP")));
            Serial.printf("   ⬇ internal-RAM lows since boot: free=%u B, largest block=%u B\n",
                (unsigned)g_minFreeInternal, (unsigned)g_minLargestBlock);
            Serial.printf("   ⬇ DMA-capable lows since boot:  free=%u B, largest block=%u B\n",
                (unsigned)g_minFreeDma, (unsigned)g_minLargestDma);
            Serial.printf("   Display=%u CAN=%u SDLog=%u\n",
                (unsigned)uxTaskGetStackHighWaterMark(
                    xTaskGetHandle("Display")),
                (unsigned)uxTaskGetStackHighWaterMark(
                    xTaskGetHandle("CAN")),
                (unsigned)uxTaskGetStackHighWaterMark(
                    xTaskGetHandle("SDLog")));
        }
    }
#endif
    // Display is handled by its own task (displayTask) — see setup().
}

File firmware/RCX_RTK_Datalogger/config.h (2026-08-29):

#pragma once
/*
 * config.h — Personal settings for RCX Datalogger
 * =================================================
 * Edit this file for your WiFi, NTRIP credentials, CAN bus pins,
 * and feature toggles.  This file will NOT be overwritten by
 * firmware updates — it lives in your sketch folder.
 */

// ── WiFi ──────────────────────────────────────────────────────────────────────
// There are NO WiFi credentials in this file, or anywhere else in the source.
// The station list is held entirely in NVS and managed from the web dashboard
// (add / remove / reorder); list order is connection priority. See wifi_mgr.h.
//
// A freshly-flashed unit therefore knows no networks — which is exactly why the
// configuration AP below is permanent. Join it, open the dashboard, add a
// network. It is also what allows a base-only field setup with no internet at
// all: the rover joins the base's AP and takes corrections directly from it.

// The device name doubles as the configuration AP's SSID. By default it is this
// prefix plus the last two eFuse MAC bytes, so two units in the same paddock
// never advertise the same name; it can be renamed from the dashboard and the
// new name persists in NVS. Keep the prefix short — name and SSID share the
// 32-character 802.11 limit.
#define DEVICE_NAME_PREFIX   "RCX Datalogger "

//
// AP passphrase. Fewer than 8 characters (the WPA2 minimum) leaves the AP OPEN,
// which is the default: a unit that has never been configured must be joinable
// without a credential the operator has no way to look up. Set a passphrase here
// if the unit will live somewhere the AP should not be open to anyone nearby.
#define WIFI_AP_PASSWORD     ""
#define WIFI_AP_CHANNEL      1
#define WIFI_AP_MAX_CLIENTS  4

// Per-network association timeout while rotating through the stored list.
#define WIFI_CONNECT_TIMEOUT_MS  20000

// After a station link drops, how long the network that was connected gets
// exclusive retries before the full priority search restarts from the top.
#define WIFI_RECONNECT_WINDOW_MS 30000

// Per-attempt association timeout inside that window. Deliberately shorter than
// WIFI_CONNECT_TIMEOUT_MS so several attempts fit in the window instead of one
// long attempt consuming the entire budget.
#define WIFI_RECONNECT_ATTEMPT_MS 10000

// Spacing between station reconnect sweeps while disconnected. Also bounds the
// idle cost of AP-only operation, where every sweep returns immediately because
// the list is empty.
#define WIFI_RETRY_INTERVAL_MS   15000

// Station power save WIFI_PS_MIN_MODEM instead of sleep-off, so the 2.4 GHz
// coexistence arbiter can grant the BLE controller its connection anchors —
// see radio-discipline rule 5 in wifi_mgr.cpp for the mechanism and the
// 2026-08-22 field evidence. false restores the always-on radio behavior.
#define WIFI_MODEM_SLEEP_FOR_COEX  true

// ── NTRIP Casters ─────────────────────────────────────────────────────────────
// columns: host, port, username, password
// Definitions live in config.cpp — add/remove rows there.
extern const char* ntripCasters[][4];
extern const int   ntripCasterCount;

// Upper bound on configured casters. The per-caster rate-limit array
// (lastCasterFetch[]) is sized to this. If you add casters to config.cpp,
// keep their total <= NTRIP_MAX_CASTERS or raise this value. scanCaster()
// bounds-checks against it so an over-count can never corrupt memory.
#define NTRIP_MAX_CASTERS  8

// Optional: preferred mountpoint for each caster, indexed to match
// ntripCasters[]. Set to your known mountpoint name to skip the full
// source-table scan and connect with top priority. Leave "" for auto-select.
// Size must always be >= ntripCasterCount.
extern const char* ntripPreferredMpt[];

// ── NTRIP Behaviour ───────────────────────────────────────────────────────────
//#define NTRIP_QUICK_THRESHOLD_DEG      0.45  //replaced with km
#define NTRIP_MAX_BASELINE_KM      100.0 //km
#define NTRIP_RESCAN_INTERVAL_MS       3600000   // 1 hr
#define NTRIP_IMPROVE_THRESHOLD        0.75
#define NTRIP_SOURCE_TABLE_MIN_INTERVAL_MS   300000
#define NTRIP_CONNECT_INITIAL_RETRY_MS        15000

// No-data watchdog: a connected mountpoint that sends zero RTCM bytes for this
// long is dead weight (healthy bases send every second) — drop and retry/fail
// over. This is what turns "connected: yes" into "connected AND functioning".
#define NTRIP_DATA_TIMEOUT_MS                 20000

// Cooldown applied to a PREFERRED mountpoint that proved bad at runtime (silent
// twice in a row, or RTCM 1005/1006 baseline beyond NTRIP_MAX_BASELINE_KM).
// While cooling down, phase-0 direct connect skips it so the geographic
// fallback (rtk2go nearest) actually gets used instead of being preempted.
#define NTRIP_PREF_COOLDOWN_MS               600000   // 10 min
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

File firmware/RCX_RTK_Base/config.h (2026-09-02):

#pragma once

// ================================================================
// ESP32-S3 LCD XBee Bridge - Base Station Configuration
// ================================================================
// Test caster connectivity from a terminal — substitute a configured caster's
// own host, mountpoint, and password:
// curl.exe -v -H "User-Agent: NTRIP Client/1.0" -H "Ntrip-Version: Ntrip/2.0" --user "MOUNT:PASSWORD" http://HOST:2101/MOUNT --output test_stream.bin

// Each unit generates its own name on first boot (from its MAC, so multiple
// units never collide) and stores it in NVS; it doubles as the fallback AP's
// SSID and is renamable from the web dashboard. See loadDeviceName().
//
// The fallback AP is deliberately OPEN and has no compile-time password. It exists so
// the dashboard stays reachable when no configured WiFi is in range — a recovery path,
// which a password the operator cannot look up would defeat. Anyone wanting the AP
// secured sets a password from the dashboard, which is stored in NVS.

// Draw LCD text twice, one pixel apart, so every glyph stem is 2 px instead of 1.
// Thin single-pixel strokes are the first thing lost in direct sunlight. The fonts are
// not anti-aliased, so this thickens the glyphs without blurring them. Set false for the
// original hairline text. See bprint().
static constexpr bool LCD_BOLD_TEXT = true;

// ── WiFi Networks ─────────────────────────────────────────────────────────────
// Configured from the web dashboard's WiFi Networks card and stored in NVS.

// ── Outbound NTRIP Source Casters (servers we push RTCM TO) ──────────────────
// Configured from the web dashboard's Casters card and stored in NVS.

// ── LG290P Base Configuration ────────────────────────────────────────────────
static constexpr uint32_t DEFAULT_SURVEY_IN_SEC = 900;
static constexpr float DEFAULT_SURVEY_IN_ACC_LIMIT_M = 3.20f;
static constexpr uint16_t LG290P_REFERENCE_STATION_ID = 290;

// Set to 1 to send LG290P base-mode + survey-in + RTCM configuration at boot.
// The firmware sends documented PQTM commands and computes NMEA checksums.
static constexpr bool LG290P_CONFIGURE_ON_BOOT = true;

// Set to true only after entering accurate externally-surveyed WGS84 ECEF meters.
static constexpr bool LG290P_USE_FIXED_BASE = false;

// Survey method for establishing a new base coordinate.
//   true  — PPP rover-mode survey (ppp_survey.*): the receiver runs as a rover with
//           Galileo E6 HAS PPP, we average only fixes that pass our own EPE gate, then
//           lock the average in as the fixed base. Better absolute accuracy, and the
//           acceptance criteria are ours to change live.
//   false — the module's internal survey-in (PQTMCFGSVIN mode 1), whose averaging and
//           completion criteria are opaque and cannot be retargeted without restarting.
// There is no fallback between the two, and none is needed: with PPP enabled the rover
// always returns the best solution the available corrections support, degrading on its
// own to an autonomous 3D fix when HAS data is weak. A survey therefore always yields a
// coordinate — the PPP-converged average when it converged, the unfiltered autonomous
// average when it did not — and the saved position records which, so the accuracy is
// never overstated.
//
// The PPP path drives ppp_survey.cpp, whose command sequence is the field-proven one
// from the 7-25-26 build and must not be "corrected" against the spec again: the
// receiver-mode switches there apply live, and PQTMEPE takes no MsgVer in that sequence.
// Setting this false falls back to the module's own internal survey-in.
static constexpr bool BASE_SURVEY_USE_PPP = true;
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

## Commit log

2026-08-29 Initial publication
    This is the first public upload for the WSP32 firmware for Arduino IDE.
2026-08-29 Updated readme.md
    Added detailed Arduino IDE setup information
2026-10-08 engineering schematics
2026-10-08 Added engineering schematic viewers
2026-10-08 Added 3D Print Models
    [RCX_RTK_Datalogger_3D_Printing_Models.3mf]
2026-10-08 Moving schematics to docs/
2026-10-08 Updated schematics
